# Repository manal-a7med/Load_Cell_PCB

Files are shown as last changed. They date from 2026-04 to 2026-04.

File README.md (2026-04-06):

# Load_Cell_PCB
HX711 Load Cell PCB Design using KiCAD 10.0

Manal Ahmed Matheen
ELECTRONICS ASSIGNMENT REPORT
Automated Food Dispensing System — Load Cell Measurement Subsystem

Task	Design Problem Statement
Domain	Embedded Systems / PCB Design
Status	Internship Technical Submission
Date	31 March 2026

Task 1 — Load Cell Selection and Key Specifications

The load cell is the primary transducer in this food dispensing system. It converts the mechanical force (weight of dispensed food) into an electrical signal. Choosing the right load cell is critical for accuracy, durability, and noise immunity in an industrial or semi-industrial environment.

1.1 Recommended Load Cell — Recommendation

✔ Selected	HX711-compatible Single-Point Load Cell (e.g., TAL220B / CZL635 / Bosche H40A) — Strain-gauge type, single-point platform cell

Reason	Strain-gauge load cells offer excellent linearity, low hysteresis, and are widely compatible with 24-bit ADC front-ends. Single-point cells are ideal for platform-style food-pan weighing.

1.2 Key Specifications to Consider

A. Load Capacity
•	Select rated capacity based on maximum expected food load plus a 20–30% safety margin.
•	For a food dispenser pan: 1 kg to 5 kg rated capacity is typical (e.g., 5 kg full-scale).
•	Overload protection rating should be ≥150% of rated capacity to survive mechanical disturbances.

B. Accuracy & Linearity
Specification targets for a reliable food-dispensing system:

Specification	Typical Requirement	Recommended Value
Non-linearity	< ±0.05% FS	< ±0.02% FS
Hysteresis	< ±0.05% FS	< ±0.02% FS
Repeatability	< ±0.05% FS	< ±0.01% FS
Temperature Effect (Zero)	< ±0.03% FS/°C	< ±0.02% FS/°C
Creep (30 min)	< ±0.03% FS	< ±0.02% FS

C. Sensitivity & Output
•	Standard bridge sensitivity: 1–3 mV/V (e.g., 2 mV/V at full rated load).
•	Bridge excitation voltage: 5V or 10V (match to ADC front-end supply).
•	Higher sensitivity = better SNR before amplification.

D. Resistance to Mechanical Disturbances
•	IP Rating: Minimum IP54 for food/dust environments; IP65 preferred.
•	Material: Aluminium alloy body (anodised) for food-grade applications; stainless steel for wet wash-down.
•	Mechanical shock rating: ≥10g or higher to withstand dispensing impacts.
•	Anti-vibration: Use rubber mounting isolators under the cell to decouple conveyor/motor vibration.

E. Electrical Noise Immunity
•	Use a 4-wire (Wheatstone bridge) or 6-wire load cell for remote sense compensation.
•	Shield the signal cable and connect the shield to a single-point earth at the MCU side.
•	Digital filtering in firmware (moving average / IIR) to suppress 50 Hz mains interference.

1.3 Comparative Summary of Load Cell Types

Type	Pros	Cons	Suitability
Strain Gauge (Single Point)	Low cost, compact, good linearity	Sensitive to off-center loads beyond cell rating	✔ Best for this application
Strain Gauge (Bending Beam)	High accuracy, robust	Larger footprint	Good alternative
Capacitive	No hysteresis, very accurate	Complex electronics, higher cost	Overkill for this use
Piezoelectric	Fast dynamic response	Cannot measure static weight accurately	✘ Not suitable

Task 2 — ADC Selection for Load Cell Signal Acquisition

Load cell output signals are extremely small (millivolt-range differential signals). A high-resolution, low-noise ADC with an integrated instrumentation amplifier front-end is required. The ADC communicates directly with the MCU.

2.1 Recommended ADC — HX711

✔ Selected	HX711 — 24-bit Sigma-Delta ADC with integrated PGA (Programmable Gain Amplifier), purpose-built for load cell / Wheatstone bridge applications

2.2 HX711 Key Specifications

Parameter	Value
Resolution	24-bit (≈16 million counts)
Input Channels	2 differential inputs (A and B)
Programmable Gain (Ch A)	128× or 64×
Programmable Gain (Ch B)	32×
Data Rate	10 SPS or 80 SPS (selectable via RATE pin)
Supply Voltage (AVDD)	2.6V – 5.5V
Supply Voltage (DVDD)	2.6V – 5.5V
Noise RMS (Ch A, Gain 128)	50 nV RMS typical
Interface	2-wire serial (PD_SCK / DOUT) — not standard SPI/I2C
Temperature Range	−40°C to +85°C
Package	SOP-16

2.3 Why HX711 Over General-Purpose ADCs
•	Integrated PGA eliminates need for an external instrumentation amplifier (reduces BOM and board space).
•	24-bit resolution provides 0.3 μV/count sensitivity at 5V excitation with gain 128 — sufficient for detecting sub-gram weight changes.
•	Differential input rejects common-mode noise from long cable runs.
•	Simple 2-wire bit-bang interface works with any MCU without SPI/I2C peripheral.
•	Low cost (~$1–2 per unit in volume), widely available, extensive community support.

2.4 Alternative High-Performance ADC — ADS1232 (Texas Instruments)

Alternative	ADS1232 — 24-bit Sigma-Delta ADC with integrated PGA, for applications requiring higher accuracy and temperature performance

Feature	HX711	ADS1232
Resolution	24-bit	24-bit
Data Rate	10 / 80 SPS	10 / 40 / 640 / 2000 SPS
Input Channels	2 differential	2 differential
Max Gain	128×	128×
Noise @ 10 SPS	~50 nV RMS	~17 nV RMS
Price (Approx.)	$1–2	$5–8
Interface	Custom 2-wire	SPI-compatible
Best For	Cost-sensitive, basic weighing	High-precision industrial weighing

For this internship system, the HX711 is the recommended choice due to its cost-effectiveness, simplicity, and adequate resolution for food dispensing applications.

Task 3 — Connectors and Cables Selection

Proper connector and cable selection is essential to maintain signal integrity for the millivolt-level load cell signals, ensure mechanical robustness, and provide EMI immunity.

3.1 Load Cell Output Cable (Load Cell → HX711/ADC)

Cable Specification

✔ Recommended	4-core shielded twisted pair (STP) cable — 24 AWG minimum, overall braid shield + foil shield, PVC or PUR jacket

Parameter	Specification
Cable Type	4-core shielded twisted pair (STP)
Conductor Gauge	24 AWG (0.205 mm²) minimum
Shielding	Braid + foil (double shield) for best EMI rejection
Jacket Material	PVC (dry environments) / PUR (wash-down / flexible routing)
Max Cable Length	≤ 3 m without additional buffering (use 6-wire for longer runs)
Color Coding (Standard)	Red=EXC+, Black=EXC−, Green=SIG+, White=SIG−, (Yellow=SEN+, Blue=SEN− for 6-wire)
Temperature Range	−20°C to +80°C

Connector at Load Cell End
•	M8 4-pin circular connector (IP65/IP67 rated) — push-pull or screw-lock.
•	Manufacturer examples: Binder Series 763, Amphenol M8, Phoenix Contact M8.
•	Use nickel-plated brass shell for corrosion resistance in food environments.

Connector at PCB/MCU End
•	Molex Micro-Fit 3.0 (2×2 or 1×4) — locking, 3A rated, vibration resistant.
•	Alternatively: JST-XH 2.54mm pitch 4-pin — lower cost, adequate for PCB prototyping.
•	For industrial boards: Phoenix Contact MSTB 2.5mm pitch screw terminal block.

3.2 HX711 → MCU Digital Interface Connections

Signal	Pin on HX711	Connector Type	Notes
PD_SCK (Clock)	Pin 11	Standard PCB header 2.54mm	Push-pull output from MCU GPIO
DOUT (Data Out)	Pin 12	Standard PCB header 2.54mm	Open-drain; add 10kΩ pull-up
VCC (DVDD)	Pin 14/15	Power header or onboard trace	3.3V or 5V from MCU regulator
GND	Pin 16	Common PCB ground	Single-point ground near ADC
AVDD (Analog)	Pin 1	Separate filtered supply	100nF + 10μF decoupling to AGND

3.3 Grounding and Shielding Best Practices
•	Connect cable shield to AGND at the PCB side only (single-point grounding prevents ground loops).
•	Separate analog ground (AGND) from digital ground (DGND); join at a single star point.
•	Route analog signal traces away from digital clock traces and switching power supply traces on the PCB.
•	Add ferrite bead (e.g., Murata BLM18AG, 600Ω @ 100MHz) on AVDD supply line to ADC.

Task 4 — Embedded Code for ADC Data Acquisition

The following code is written for the Arduino Uno (ATmega328P) MCU using the Arduino framework. It interfaces with the HX711 24-bit ADC via bit-banging the custom 2-wire serial protocol. The code includes tare (zero offset), scale calibration, moving average filtering, and serial output.

4.1 HX711 Hardware Interface Protocol
The HX711 uses a proprietary clock-gated serial protocol. When DOUT goes LOW, data is ready. The MCU generates 24 rising edges on PD_SCK to clock out 24 data bits MSB-first, followed by 1–3 additional pulses to configure channel and gain for the next conversion.

4.2 Complete Arduino Firmware

/*
 * HX711 Load Cell ADC Interface — Food Dispensing System
 * MCU: Arduino Uno (ATmega328P)
 * Author: Engineering Intern
 * Date: 2024
 */

#include <Arduino.h>

// ─── Pin Definitions ──────────────────────────────────────
#define HX711_DOUT    2    // Data Out pin (INT0 for optional interrupt use)
#define HX711_SCK     3    // Serial Clock pin

// ─── Configuration ────────────────────────────────────────
#define HX711_GAIN    1    // 1 = Ch A Gain 128 (2 pulses extra)
                           // 2 = Ch B Gain 32  (3 pulses extra)
                           // 3 = Ch A Gain 64  (4 pulses extra)
#define SAMPLES       10   // Moving average window size
#define SERIAL_BAUD   115200

// ─── Calibration Constants ────────────────────────────────
long   tareOffset  = 0;        // Set by tare() function
float  scaleGram   = 410.0f;   // Counts per gram (calibrate empirically)

// ─── Function: Read raw 24-bit signed value from HX711 ─────
long hx711_read_raw(void) {
  // Wait until data ready (DOUT goes LOW)
  while (digitalRead(HX711_DOUT) == HIGH);

  long data = 0;

  // Clock out 24 bits, MSB first
  for (uint8_t i = 0; i < 24; i++) {
    digitalWrite(HX711_SCK, HIGH);
    delayMicroseconds(1);
    data = (data << 1) | digitalRead(HX711_DOUT);
    digitalWrite(HX711_SCK, LOW);
    delayMicroseconds(1);
  }

  // Extra pulses to configure gain for next reading
  for (uint8_t i = 0; i < HX711_GAIN; i++) {
    digitalWrite(HX711_SCK, HIGH);
    delayMicroseconds(1);
    digitalWrite(HX711_SCK, LOW);
    delayMicroseconds(1);
  }

  // Sign-extend 24-bit two's complement to 32-bit
  if (data & 0x800000) {
    data |= 0xFF000000;  // Extend sign bit
  }

  return data;
}

// ─── Function: Moving Average Filter ──────────────────────
long hx711_read_average(uint8_t n) {
  long sum = 0;
  for (uint8_t i = 0; i < n; i++) {
    sum += hx711_read_raw();
  }
  return sum / n;
}

// ─── Function: Set tare (zero point) ──────────────────────
void tare(void) {
  Serial.println("Taring... ensure pan is EMPTY.");
  delay(1000);
  tareOffset = hx711_read_average(20);  // Average 20 readings for stable zero
  Serial.print("Tare offset set: ");
  Serial.println(tareOffset);
}

// ─── Function: Get weight in grams ────────────────────────
float get_weight_grams(void) {
  long raw = hx711_read_average(SAMPLES) - tareOffset;
  return (float)raw / scaleGram;
}

// ─── Function: Power down HX711 (sleep mode) ──────────────
void hx711_power_down(void) {
  digitalWrite(HX711_SCK, LOW);
  digitalWrite(HX711_SCK, HIGH);
  delayMicroseconds(65);  // Hold SCK HIGH >60μs to enter power-down
}

// ─── Function: Wake up HX711 ──────────────────────────────
void hx711_power_up(void) {
  digitalWrite(HX711_SCK, LOW);
  delay(500);  // Allow ADC to settle after wake
}

// ─── Setup ────────────────────────────────────────────────
void setup() {
  Serial.begin(SERIAL_BAUD);
  pinMode(HX711_DOUT, INPUT);
  pinMode(HX711_SCK, OUTPUT);
  digitalWrite(HX711_SCK, LOW);

  Serial.println("===================================");
  Serial.println(" Food Dispenser Load Cell System  ");
  Serial.println("===================================");
  delay(500);

  tare();  // Zero the scale on startup

  Serial.println("System ready. Monitoring weight...");
  Serial.println("-----------------------------------");
}

// ─── Main Loop ────────────────────────────────────────────
void loop() {
  float weight = get_weight_grams();

  Serial.print("Weight: ");
  Serial.print(weight, 2);
  Serial.println(" g");

  // Optional: threshold alarm for target dispensing weight
  const float TARGET_GRAMS = 200.0f;
  const float TOLERANCE    = 2.0f;

  if (weight >= (TARGET_GRAMS - TOLERANCE) &&
      weight <= (TARGET_GRAMS + TOLERANCE)) {
    Serial.println(">>> TARGET WEIGHT REACHED — Stop dispensing!");
  }

  delay(200);  // 5 Hz update rate (HX711 at 80 SPS with 10-sample average)
}

4.3 Calibration Procedure
1.	Remove all weight from the pan and power on the system.
2.	The tare() function runs automatically at startup — establishes zero reference.
3.	Place a known calibration weight (e.g., exactly 200 g certified weight) on the pan.
4.	Read the raw value via Serial Monitor.
5.	Calculate: scaleGram = raw_reading / known_weight_in_grams
6.	Update the scaleGram constant in firmware and reflash.
7.	Verify accuracy with additional reference weights across the measurement range.

4.4 Key Firmware Design Features
Feature	Implementation	Purpose
Moving Average Filter	hx711_read_average(N)	Reduce noise from vibration & EMI
Sign Extension	Two's complement 24→32 bit	Correct negative weight readings
Tare / Zero Offset	tareOffset subtraction	Compensate for pan weight
Scale Factor	Float division by scaleGram	Convert raw counts to grams
Power Management	hx711_power_down/up()	Reduce current between measurements
Target Detection	Threshold ± tolerance check	Trigger dispenser stop signal

Task 5 — PCB Design: Schematics and Board Files

The PCB integrates the HX711 ADC, power regulation, EMI filtering, MCU interface connector, and load cell connector. The design follows mixed-signal PCB best practices to ensure clean analog measurements.

5.1 PCB Design Tool Recommendation

✔ Recommended Tool	KiCad 7.0 (Open-source, professional-grade EDA) — Full schematic + PCB layout with Gerber export for manufacturing

5.2 Block-Level System Schematic Description

The schematic is organized into the following functional blocks:
•	Block 1 — Power Supply: 5V input (USB or barrel jack) → AMS1117-3.3 LDO regulator → 3.3V rail for MCU digital section. Separate ferrite-bead-isolated AVDD (5V analog) for HX711 reference input.
•	Block 2 — Load Cell Interface: M8 4-pin connector → 100nF decoupling capacitors on EXC+/EXC− → HX711 INNA/INNB inputs. Shield connected to AGND via 1MΩ resistor.
•	Block 3 — HX711 ADC: SOP-16 IC, AVDD decoupled with 10μF tantalum + 100nF MLCC. DVDD separate from AVDD with ferrite bead isolation. RATE pin tied to GND (10 SPS, lower noise mode).
•	Block 4 — MCU Interface: 4-pin 2.54mm header for DOUT, PD_SCK, VCC, GND to Arduino Uno or custom MCU board. 10kΩ pull-up on DOUT line.
•	Block 5 — Protection & Filtering: TVS diode (PRTR5V0U2X) on load cell signal lines. Common-mode choke on EXC supply lines.

5.3 Component Bill of Materials (BOM)

Ref.	Component	Value / Part No.	Package	Quantity
U1	ADC	HX711	SOP-16	1
U2	LDO Regulator	AMS1117-3.3	SOT-223	1
J1	Load Cell Connector	M8 4-pin female PCB	M8 THT	1
J2	MCU Header	Pin Header 1×4	2.54mm THT	1
J3	Power Input	Micro-USB / Barrel Jack	THT	1
C1, C2	AVDD Decoupling	10μF Tantalum	SMD 1206	2
C3–C6	Bypass Caps	100nF MLCC X7R	SMD 0402	4
R1	DOUT Pull-up	10kΩ	SMD 0402	1
R2	Shield Bleed	1MΩ	SMD 0402	1
FB1	Ferrite Bead	600Ω@100MHz (Murata BLM18AG)	SMD 0402	1
D1	ESD Protection	PRTR5V0U2X TVS	SOT-363	1

5.4 PCB Layout Guidelines

Layer Stack-up (2-layer board)
•	Top Layer (Signal): Component placement, analog signal routing, digital routing.
•	Bottom Layer (Ground Plane): Solid copper pour for GND — reduces impedance and acts as EMI shield.

Critical Routing Rules
Rule	Value / Method
Analog signal trace width	0.2 mm minimum (keep short, direct)
Digital signal trace width	0.2 mm
Power trace width	0.8 mm minimum (1.0 mm for 5V input)
Analog/Digital separation	Physical split in ground plane, joined at single star point
HX711 AVDD decoupling placement	< 3 mm from AVDD pin — C1/C2 placed first in routing
Load cell signal routing	Differential pair, matched length, away from clock traces
Trace clearance (EXC to SIG)	≥ 0.2 mm to prevent cross-talk
Silkscreen	Label all connectors, test points, and polarity markers

5.5 PCB Manufacturing Specifications

Specification	Value
Board Size	60 mm × 40 mm initially, but changed later.
Layer Count	2 (signal + ground plane)
Board Material	FR4 1.6 mm
Copper Weight	1 oz (35 μm)
Surface Finish	HASL (Hot Air Solder Level) or ENIG for fine-pitch pads
Solder Mask	Green (or blue for identification)
Silkscreen	White (both sides)
Gerber Files Required	F.Cu, B.Cu, F.Mask, B.Mask, F.SilkS, Edge.Cuts, drill file (.drl)

PLESE NOTE :-
 A barrel jack power input connector (CUI PJ-102AH) is recommended for the production version to provide a dedicated 5V supply input. In this prototype version, 5V power is supplied directly through the J2 MCU connector Pin 3.

5.6 Test Plan for PCB Validation
Visual Inspection: Check all solder joints, no shorts or bridges under magnification.

Power-On Test: Apply 5V, measure 3.3V rail (expect 3.3V ±2%), verify AVDD (expect 5V               ±1%).

HX711 Communication Test: Flash firmware, check Serial Monitor for valid (non-zero) readings.

Noise Floor Test: Short INNA/INNB inputs, record raw values — noise floor should be < ±5 counts.

Load Cell Integration Test: Connect reference load cell, apply known weights, verify accuracy.

Vibration Test: Apply mechanical disturbances, confirm moving-average filter rejects spikes.

Temperature Soak: Run at 10°C and 50°C, verify < ±0.05% FS reading drift.

References & Standards

•	HX711 Datasheet — Avia Semiconductor, Rev 1.0. 24-Bit Analog-to-Digital Converter for Weigh Scales.
•	ADS1232 Datasheet — Texas Instruments, SBAS424. 24-Bit Analog-to-Digital Converter.
•	OIML R 60 — International Recommendation for Metrological Regulation of Load Cells.
•	IEC 61000-4-5 — Electromagnetic Compatibility: Surge Immunity Requirements.
•	KiCad EDA Documentation — https://docs.kicad.org, Version 7.0.
•	Analog Devices MT-031 Tutorial — Grounding Data Converters and Solving the Mystery of 'AGND' and 'DGND'.
•	Arduino Reference Documentation — https://www.arduino.cc/reference/en/
•	Phoenix Contact MSTB Connector Series Datasheet — Phoenix Contact GmbH.

— End of Report —

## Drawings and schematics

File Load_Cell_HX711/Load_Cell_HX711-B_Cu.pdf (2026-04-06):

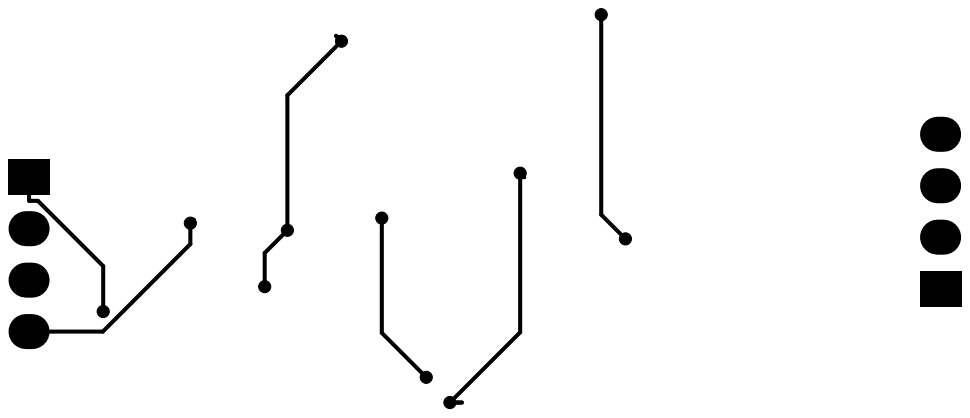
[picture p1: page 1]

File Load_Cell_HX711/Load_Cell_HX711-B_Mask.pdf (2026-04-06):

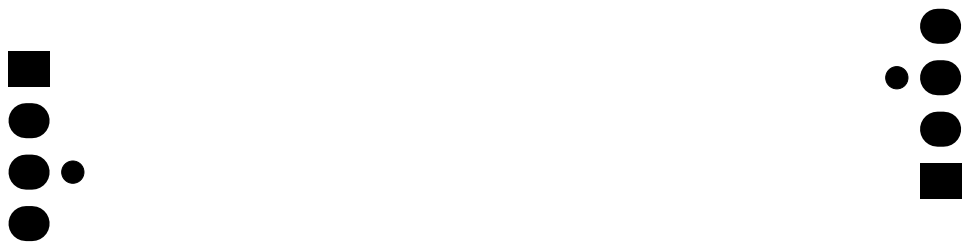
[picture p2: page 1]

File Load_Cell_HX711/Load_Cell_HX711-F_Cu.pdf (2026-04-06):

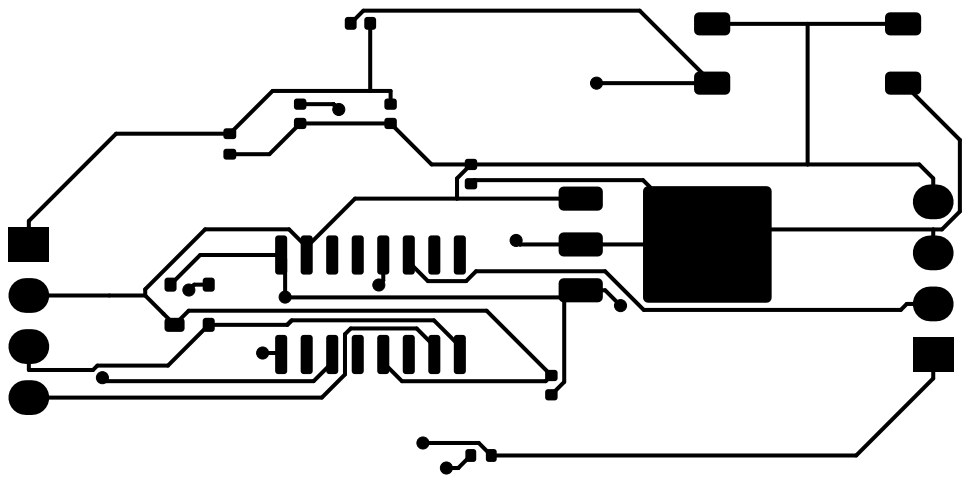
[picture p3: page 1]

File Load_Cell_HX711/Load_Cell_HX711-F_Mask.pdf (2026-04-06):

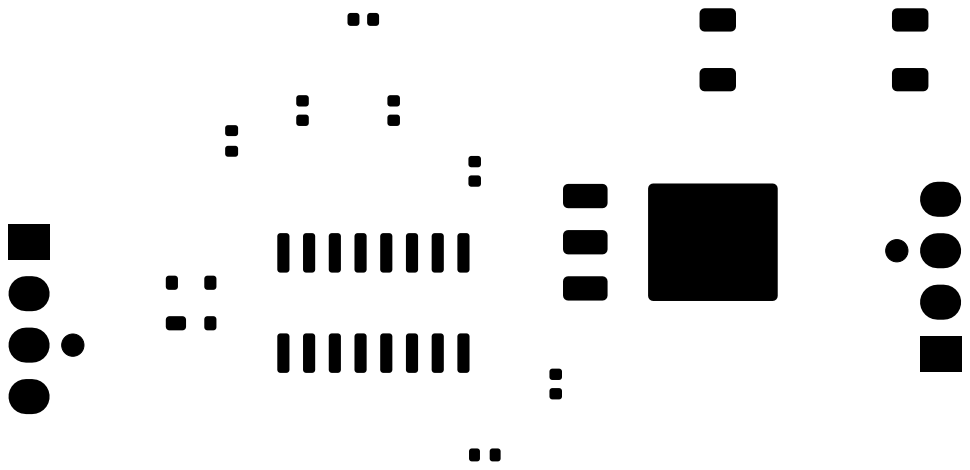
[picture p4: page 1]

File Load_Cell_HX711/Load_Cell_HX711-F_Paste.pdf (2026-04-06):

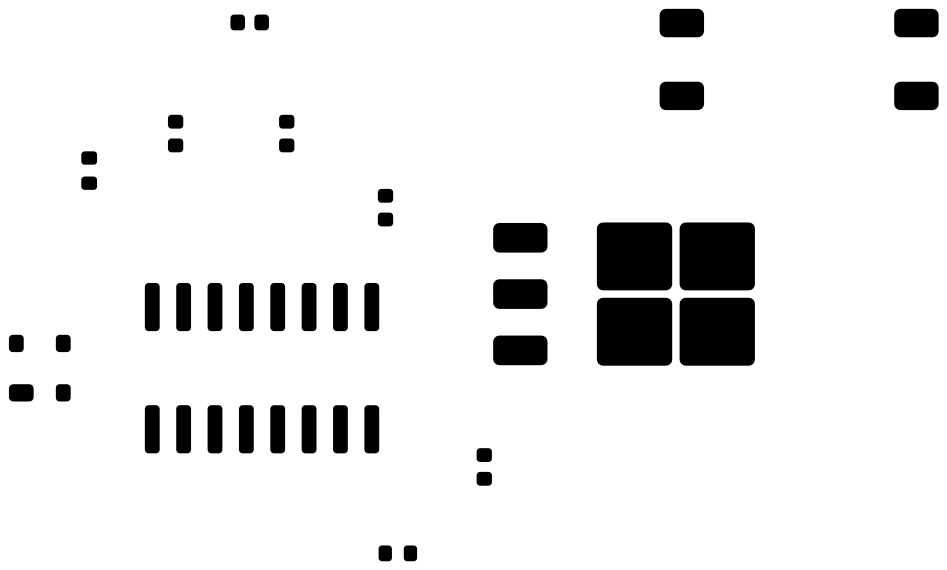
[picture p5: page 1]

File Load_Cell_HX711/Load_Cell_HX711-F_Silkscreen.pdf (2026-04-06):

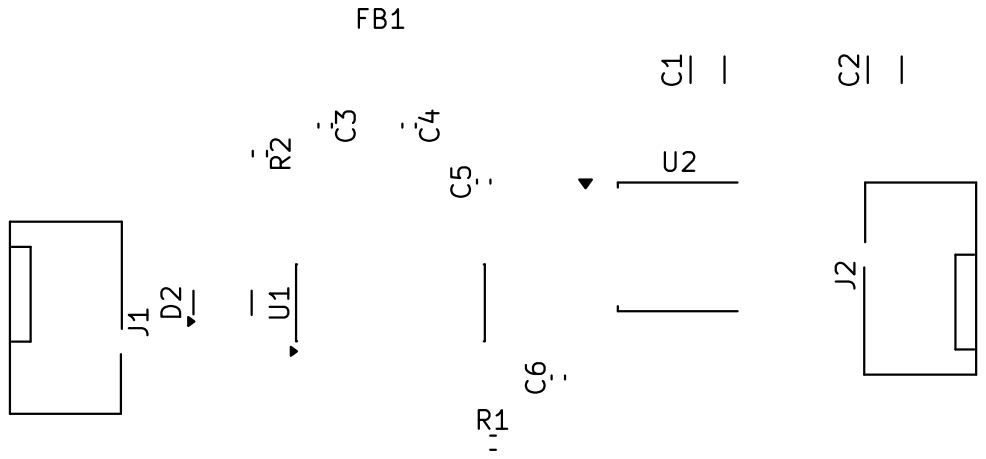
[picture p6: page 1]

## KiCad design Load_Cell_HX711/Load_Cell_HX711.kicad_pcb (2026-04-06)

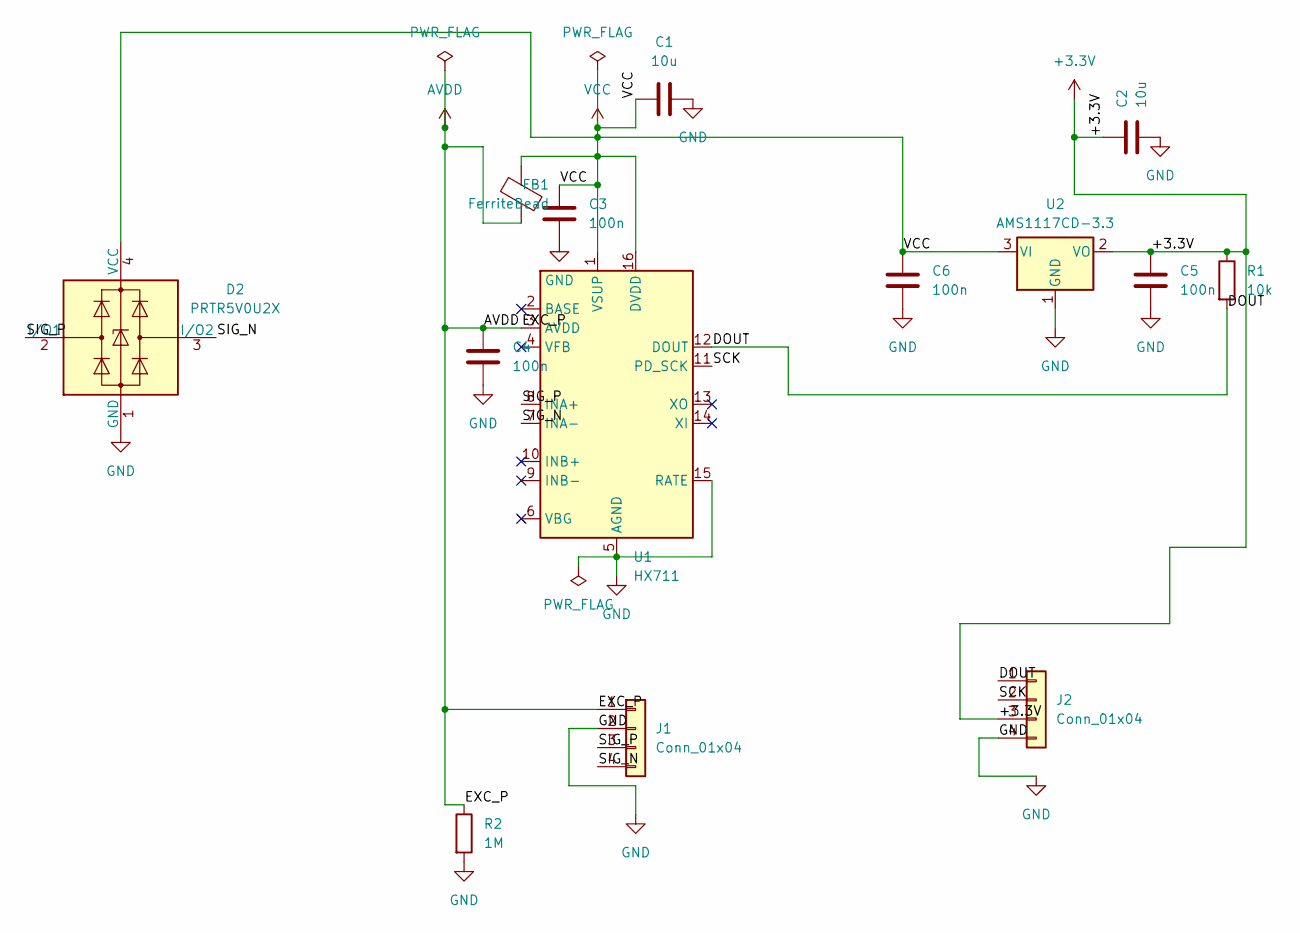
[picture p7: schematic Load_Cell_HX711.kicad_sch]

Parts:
C1, C2: 10u; C_1206_3216Metric
C3, C4, C5, C6: 100n; C_0402_1005Metric
D2: PRTR5V0U2X; SOT-143
FB1: FerriteBead; L_0402_1005Metric
J1, J2: Conn_01x04; FanPinHeader_1x04_P2.54mm_Vertical
R1: 10k; R_0402_1005Metric
R2: 1M; R_0402_1005Metric
U1: HX711; SOIC-16_3.9x9.9mm_P1.27mm
U2: AMS1117CD-3.3; TO-252-3_TabPin2

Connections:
+3.3V: C2.1, C5.1, J2.3, R1.1, U2.2 (VO)
/DOUT: J2.1, R1.2, U1.12 (DOUT)
/SCK: J2.2, U1.11 (PD_SCK)
/SIG_N: D2.3 (I/O2), J1.4, U1.7 (INA-)
/SIG_P: D2.2 (I/O1), J1.3, U1.8 (INA+)
AVDD: C4.1, FB1.2, J1.1, R2.1, U1.3 (AVDD)
GND: C1.2, C2.2, C3.2, C4.2, C5.2, C6.2, D2.1 (GND), J1.2, J2.4, R2.2, U1.5 (AGND), U1.15 (RATE), U2.1 (GND)
VCC: C1.1, C3.1, C6.1, D2.4 (VCC), FB1.1, U1.1 (VSUP), U1.16 (DVDD), U2.3 (VI)

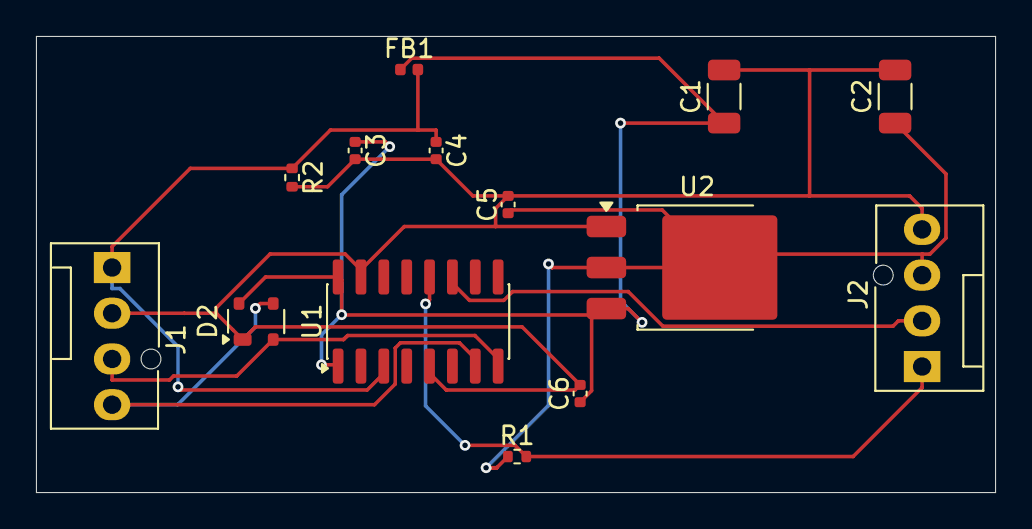
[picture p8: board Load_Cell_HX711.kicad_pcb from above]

Board: 2 copper layers, 53.3 x 25.3 mm, 14 parts (0 on the bottom side), 8 nets.
